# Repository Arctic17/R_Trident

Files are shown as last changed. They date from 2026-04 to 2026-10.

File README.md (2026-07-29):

<h1 align="left">
  <br>
  
  <br>
  R Trident: 
  
  High-Speed Rotary Delta Robot
</h1>

Every successful project starts with a goal, and this one is no different. My objective is to design and build a Rotary Delta kinematic motion system from the ground up covering feasibility research, groundwork, development, manufacturing, and programming, through to final assembly.
But why?
The purpose is twofold: to deepen my understanding of systems integration across multiple disciplines and to
refine my ability to manage every stage of a complex engineering project from start to finish.

So it can be summeriesed like this

R_Trident is a high-performance, direct-drive Rotary Delta Robot built using three **AC Servo Motors (A6M60-400H2B1-M17)** paired with real-time **EtherCAT** communications. The control system runs on a custom **Raspberry Pi** executing a hard **real-time** LinuxCNC kernel.

## System Architecture Overview

* **Host Controller:** Raspberry Pi CM5 (Real-Time Preempt Kernel)
* **Fieldbus:** EtherCAT (IgH EtherCAT Master Stack) @ 1ms loop time
* **Actuation:** 3x Direct-Drive 400W AC Servos (No gearboxes, peak torque 4.45 Nm)
* **Feedback Loops:** 17-bit absolute magnetic encoder feedback over CoE (CANopen over EtherCAT)

---

## Documentation Index

To read or modify specific engineering subsystems, navigate to the sub-files listed below:

1. [Mathematical Kinematics & Control Math](docs/01_mathematical_kinematics.md)
   * Spatial loops, 3D vector intersections, Simulink models, PID tuning data, and Z-axis trajectory bowing fixes.
2. [Mechanical Design & Topology Optimization](docs/02_mechanical_design.md)
   * Inventor 2025 System assembly and machined parts plans. Fusion 360 generative setup, weight metrics, load cases, filament selection.
3. [Electronics & Breakout Architecture](docs/03_electronics_breakout.md)
   * Dual Ethernet paths, isolated logic rails, buck converters, and headless hardware diagnostics interfaces.
4. [Electrical Cabinet Engineering](docs/04_electrical_cabinet.md)
   * 4-row layout, star distribution wiring, emergency interlocks without STO, and grounding trees.
5. [LinuxCNC & EtherCAT Drive Stack Setup](docs/05_linuxcnc_ethercat.md)
   * Host configuration, drive parameters, `ethercat-conf.xml` mapping, and `.hal` files.

## File structure

All custom files and entries in the BOM follow the **RT_XXX_YY_000_Name** naming system.

### Schema 
**`RT`** (Project) _ **`XXX`** (System) _ **`YY`** (Category) _ **`000`** (Index) _ **`Name`**

| System Code (XXX) | Description | Category Code (YY) | Description |
| :--- | :--- | :--- | :--- |
| **FRM** | Frame & Structure | **PR** | 3D Printed Part |
| **DRV** | Drive Train (Shoulder) | **MC** | Machined / Laser Cut |
| **ARM** | Biceps & Forearms | **CO** | Commercial (Off-the-shelf) |
| **EFF** | Effector & Hotend | **SK** | Skeleton / Reference |
| **BED** | Bed & Z-Axis | **AS** | Sub-Assembly |
| **ENC** | Enclosure | **EL** | Electronics Component |

---

## Project Navigation

* **`01_Management`**: Costs, Sourcing (Mädler/StepperOnline), and CDC.
* **`02_CAD`**: 
    * `00_Skeleton`: Master geometry and trig parameters.
    * `03_Parts_Custom`: All `RT_XXX_PR` and `RT_XXX_MC` files.
    * `05_Top_Assembly`: The "Digital Twin" (The complete machine).
* **`04_Electronics`**: Wiring schematics and pinout maps for the BIQU Manta.
* **`05_Firmware`**: Klipper `printer.cfg` and kinematic math.
* **`06_Outputs`**: Ready-to-print STLs and production drawings.

---

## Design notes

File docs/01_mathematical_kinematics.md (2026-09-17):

# 01. Mathematical Kinematics & Control Optimization

To start, we need to establish some groundwork. A standard machine uses a Cartesian motion system, where a movement in X requires only the corresponding axis to move to achieve a translation. While this can become complicated if different coordinate systems are used for the "World" and the Effector, that remains an edge case.

<div align="center">
<figure>
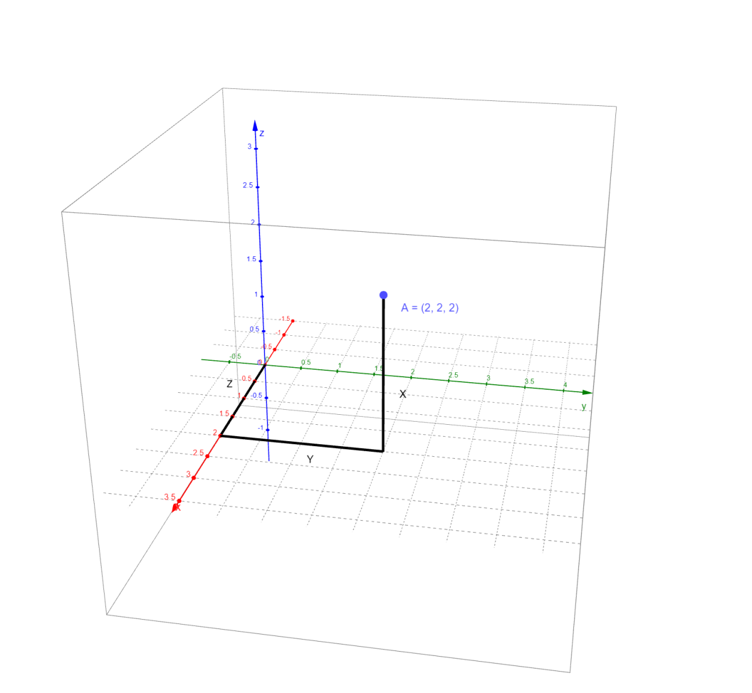
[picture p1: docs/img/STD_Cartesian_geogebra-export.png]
Standard cartesian representation of a point.
    
    <figcaption> 
        
        Example of a cartesian motion system.
</figcaption>
</figure>
</div>

Non-Cartesian systems, on the other hand, require mathematical computation to determine movement. A simple example is a two-link arm: a stick pivoting around a point with a second stick pivoting at its end. In this setup, you can reach any point in a 2D space. By knowing the angles of the two joints, you can calculate the coordinates of the end effector on the second link (SCARA).
This is the foundation of a Non-Cartesian system. It allows movement in 2D or 3D space but requires knowing the relative position of every part to extract the XYZ coordinates.

Delta systems are a subcategory where the "tool" (effector) is positioned in 3D space using three linkages that move along the same primary axes. By combining the movement of these three linkages, the effector's location is determined.
Rotary Deltas are a further sub-specialization, where the angle of a "bicep" and the lengths of the linked rods
dictate the final position.

## Spatial Kinematics Foundation

The Revolute-Input Delta Robot kinematics must be resolved using intersecting spheres in 3D coordinate space.

### The Vector Loop Equation

The primary equation for each of the three independent kinematic chains ($i = 1, 2, 3$) is modeled as:

$$\vec{B}_i + \vec{L}_i + \vec{l}_i = \vec{P}_e + \vec{P}_i$$

Where:

* $\vec{B}_i$: Vector from world coordinate origin to base joint $i$.
* $\vec{L}_i$: Vector representing the upper arm (bicep).
* $\vec{l}_i$: Vector representing the parallel spatial link (forearm pair).
* $\vec{P}_e$: Position vector of the tool-center point (TCP) end-effector.
* $\vec{P}_i$: Offset vector of joint attachment on the moving platform.

### Physical Design Constraints Matrix

* **Base Triangle Inscribed Radius ($s_B$):** 80 mm
* **Moving Platform Radius ($s_P$):** 35 mm
* **Upper Arm Length ($L$):** 150 mm
* **Lower Spatial Link Length ($l$):** 335 mm

---

## 2. Simulink modeling

To help with the complex mathematics used in this type of motion system a matlab project was created.
The systeme was split into multiple parts to aide in debugging. The parts are as followed 

* Main System View
  * Path generation
    * Random Pick and Place path generation.
    * Square path generation.
    * Circular path generation
  * Inverse Kinematics block translating ${x,y,z}$ coordinates to angles ${ \theta_1 , \theta_2 , \theta_3 }$.
  * PID
    * $PID_1$
    * $PID_2$
    * $PID_3$
  * Physical Model
    * Phsical-linkages$_1$
    * Phsical-linkages$_2$
    * Phsical-linkages$_3$
  * Forward Kinematics
  * Scopes

<div align="center">
<figure>
    
    <figcaption> MatLab Simulink model of the delta kinematics</figcaption>
</figure>
</div>

<div align="center">
<figure>
    
    <figcaption> MatLab Simscape model of the over all physical model linkages</figcaption>
</figure>
</div>

<div align="center">
<figure>
    
    <figcaption> MatLab Simscape model of the phsical linkages</figcaption>
</figure>
</div>

---

## 3. Path Tracking Dynamics & Z-Axis Bowing Correction

During fast linear XY translations, the end-effector can experience structural "bowing" along the Z-axis. This path error occurs because pure PID feedback loops react *after* tracking errors manifest.

### Velocity Feed-Forward (VFF)

To resolve this, the commanded trajectory velocity is passed through an active derivative block, scaled, and added directly to the control effort output:

```text
Commanded Pos ──> [Trajectory Planner] ──> Joint Angle ──> (+) ──> [Servo Drive]
                                               │           ^
                                               └──> [VFF] ─┘

```

Reference Control ParametersProportional Gain ($K_p$): 40
Integral Gain ($K_i$): 1.5
Derivative Gain ($K_d$): 4
Derivative Filter Coefficient ($N_d$): 100
Feed-Forward Coefficient ($K_{\text{vff}}$): 0.85

## Kinematic Architecture Flowchart

```mermaid
graph TD
    subgraph Coordinate Spaces
        W[World Origin 0,0,0] --> Bi[Base Joint Offset Vector: Bi]
        Bi --> Angle[Actuator Angle: theta_i]
        Angle --> L[Upper Arm Vector: Li]
        L --> Elbow[Elbow Joint Sphere Center]
    end

    subgraph Tool Platform
        TCP[Tool Center Point: Pe] --> Pi[Platform Joint Offset Vector: Pi]
        Pi --> Wrist[Wrist Joint Sphere Center]
    end

    Elbow ====>|Spatial Link Constraint: l| Wrist
```

# Mathematical Kinematics and Coordinate Frameworks for Rotary Delta Robot

This document establishes the geometric foundations, coordinate reference systems, and algebraic formulations required to model, simulate, and control the parallel kinematics engine of the high-speed Rotary Delta robot based on your custom physical dimensions.

Traditional 2D simplification methods (such as the law of cosines projected onto independent swinging planes) introduce severe kinematic warping when the robot transitions along its operational $X/Y$ boundaries. This warping occurs because the lower parallel linkages angle outwards into the 3D workspace domain. To guarantee micro-step tracking precision and eliminate path distortion, true spatial intersections are resolved algebraically using vector loop closures and intersecting sphere equations.

---

## System Geometry and Reference Frames

The architecture features a stationary upper platform (fixed base) and a translating lower platform (moving end-effector). Three symmetric closed-loop chains connect these platforms. Each chain consists of an actuated proximal link (bicep $L$) driven by a direct-drive servomotor and an unactuated parallel distal link (forearm parallelogram $l$).

### Coordinate Frame Assignments

* **Fixed Base Frame $\{B\}$:** The origin $O$ is positioned precisely at the planar center of the base platform. The $+Z_B$ axis points vertically upward, perpendicular to the base plane. The $+Y_B$ axis projects orthogonally toward the mid-point of the segment connecting revolute joint joints $B_2$ and $B_3$, forcing the first motor axis ($B_1$) to lie along the negative $Y_B$ axis.
* **Moving Platform Frame $\{P\}$:** The origin $P$ sits at the planar center of the moving end-effector platform. Because the parallelogram four-bar mechanisms eliminate all rotational degrees of freedom, the moving platform reference frame remains perfectly parallel to the fixed base frame across the entire reachable workspace ($[R_P^B] = I_3$).

### System Parameter Matrix

The following dimensional properties define your physical hardware build used for structural simulation, kinematic calculation, and control loop tuning:

| Variable | Mechanical Description | Value (mm) |
| :--- | :--- | :--- |
| $R_B$ | Base Pivot Circle Radius (Center to Motor Axis) | $80\text{ mm}$ |
| $R_P$ | End-Effector Radius (Center to Joint Axis) | $35\text{ mm}$ |
| $L$ | Upper Proximal Arm Length (Bicep) | $150\text{ mm}$ |
| $l$ | Lower Distal Arm Length (Forearm Parallelogram) | $335\text{ mm}$ |

---

## Vector Loop Closure Equations

For each of the independent arms ($i = 1, 2, 3$), a closed vector loop maps the geometric path from the central base origin to the tool center point (TCP) $P_e^B = [x, y, z]^T$:

$$\vec{B}_i^B + \vec{L}_i^B + \vec{l}_i^B = \vec{P}_e^B + [R_P^B]\vec{P}_i^P$$

Given that the orientation is constrained to translation-only ($[R_P^B] = I_3$), the vector equation simplifies to:

$$\vec{l}_i^B = \vec{P}_e^B + \vec{P}_i^P - \vec{B}_i^B - \vec{L}_i^B$$

### Fixed Base Angular Layout

The positions of the three base joints $\vec{B}_i^B$ are spaced symmetrically at $120^\circ$ intervals around the $Z_B$ axis at radius $R_B = 80\text{ mm}$:

$$\vec{B}_1^B = \begin{bmatrix} 0 \\ -R_B \\ 0 \end{bmatrix}, \quad \vec{B}_2^B = \begin{bmatrix} R_B\cos(30^\circ) \\ R_B\sin(30^\circ) \\ 0 \end{bmatrix}, \quad \vec{B}_3^B = \begin{bmatrix} -R_B\cos(30^\circ) \\ R_B\sin(30^\circ) \\ 0 \end{bmatrix}$$

Substituting $R_B = 80$:

$$\vec{B}_1^B = \begin{bmatrix} 0 \\ -80 \\ 0 \end{bmatrix}, \quad \vec{B}_2^B = \begin{bmatrix} 40\sqrt{3} \\ 40 \\ 0 \end{bmatrix}, \quad \vec{B}_3^B = \begin{bmatrix} -40\sqrt{3} \\ 40 \\ 0 \end{bmatrix}$$

### Moving Platform Connection Layout

The lower connection points $\vec{P}_i^P$ mapping the parallel joint attachments on the end-effector are defined relative to frame $\{P\}$ at radius $R_P = 35\text{ mm}$:

$$\vec{P}_1^P = \begin{bmatrix} 0 \\ -R_P \\ 0 \end{bmatrix}, \quad \vec{P}_2^P = \begin{bmatrix} R_P\cos(30^\circ) \\ R_P\sin(30^\circ) \\ 0 \end{bmatrix}, \quad \vec{P}_3^P = \begin{bmatrix} -R_P\cos(30^\circ) \\ R_P\sin(30^\circ) \\ 0 \end{bmatrix}$$

Substituting $R_P = 35$:

$$\vec{P}_1^P = \begin{bmatrix} 0 \\ -35 \\ 0 \end{bmatrix}, \quad \vec{P}_2^P = \begin{bmatrix} 17.5\sqrt{3} \\ 17.5 \\ 0 \end{bmatrix}, \quad \vec{P}_3^P = \begin{bmatrix} -17.5\sqrt{3} \\ 17.5 \\ 0 \end{bmatrix}$$

### Proximal Arm Joint Position

The bicep vector $\vec{L}_i^B$ is defined by the angular variables $\vartheta = [\theta_1, \theta_2, \theta_3]^T$, representing the motor rotation angles measured relative to the horizontal base plane:

$$\vec{L}_1^B = \begin{bmatrix} 0 \\ -L\cos\theta_1 \\ -L\sin\theta_1 \end{bmatrix}, \quad \vec{L}_2^B = \begin{bmatrix} L\cos\theta_2\cos(30^\circ) \\ L\cos\theta_2\sin(30^\circ) \\ -L\sin\theta_2 \end{bmatrix}, \quad \vec{L}_3^B = \begin{bmatrix} -L\cos\theta_3\cos(30^\circ) \\ L\cos\theta_3\sin(30^\circ) \\ -L\sin\theta_3 \end{bmatrix}$$

Substituting $L = 150$:

$$\vec{L}_1^B = \begin{bmatrix} 0 \\ -150\cos\theta_1 \\ -150\sin\theta_1 \end{bmatrix}, \quad \vec{L}_2^B = \begin{bmatrix} 75\sqrt{3}\cos\theta_2 \\ 75\cos\theta_2 \\ -150\sin\theta_2 \end{bmatrix}, \quad \vec{L}_3^B = \begin{bmatrix} -75\sqrt{3}\cos\theta_3 \\ 75\cos\theta_3 \\ -150\sin\theta_3 \end{bmatrix}$$

---

## Inverse Spatial Kinematics

The inverse kinematics problem calculates the required joint angles $\theta_i$ for a given tool coordinate $P_e^B = [x, y, z]^T$. Because the mechanical constraint locks each forearm parallelogram to a constant distance, the norm of the distal vector must always equal $l$ ($\|\vec{l}_i^B\|^2 = l^2$).

Substituting your vector definitions into the length constraint yields three independent scalar equations:

$$E_i\cos\theta_i + F_i\sin\theta_i + G_i = 0 \quad (i = 1, 2, 3)$$

Where the geometric constant terms for your specific dimensions ($L=150, l=335, R_B=80, R_P=35$) simplify to:

* **Arm 1:**
  $$E_1 = 2L(y + R_B - R_P) = 300(y + 45)$$
  $$F_1 = 2zL = 300z$$
  $$G_1 = x^2 + y^2 + z^2 + (R_B - R_P)^2 + L^2 - l^2 + 2y(R_B - R_P)$$
  $$G_1 = x^2 + y^2 + z^2 + 90y - 87700$$

* **Arm 2:**
  $$E_2 = -150\left(\sqrt{3}x + y - 45\right)$$
  $$F_2 = 300z$$
  $$G_2 = x^2 + y^2 + z^2 - 45\sqrt{3}x - 45y - 87700$$

* **Arm 3:**
  $$E_3 = 150\left(\sqrt{3}x - y + 45\right)$$
  $$F_3 = 300z$$
  $$G_3 = x^2 + y^2 + z^2 + 45\sqrt{3}x - 45y - 87700$$

### Trigonometric Half-Angle Substitution

To extract the raw angles without sign ambiguity, the equations are converted into a quadratic using the tangent half-angle substitution:

$$t_i = \tan\left(\frac{\theta_i}{2}\right), \quad \cos\theta_i = \frac{1 - t_i^2}{1 + t_i^2}, \quad \sin\theta_i = \frac{2t_i}{1 + t_i^2}$$

Substituting these terms into the compact form yields the standard quadratic equation:

$$(G_i - E_i)t_i^2 + (2F_i)t_i + (G_i + E_i) = 0$$

Solving for $t_i$ via the quadratic formula:

$$t_i = \frac{-F_i \pm \sqrt{F_i^2 - G_i^2 + E_i^2}}{G_i - E_i}$$

The joint angles are found directly by computing the inverse mapping:

$$\theta_i = 2\tan^{-1}(t_i)$$

### Physical Branch Selection

The quadratic formula yields two solutions per arm, representing the "knee-in" and "knee-out" mechanical configurations. To prevent collisions between the physical links and the moving platform, the controller enforces the **knee-out** branch by choosing the negative root option for the tracking loop.

---

## Forward Spatial Kinematics (Intersection of Three Spheres)

Direct kinematics calculates the operational position $[x, y, z]^T$ of the end-effector platform when the joint variables $\theta_i$ are provided. This is solved analytically by treating the end-effector position as the intersection point of three virtual spheres.

Given the joint angles $\theta_i$, the absolute spatial coordinates of the physical knee joints $\vec{A}_i^B$ are calculated directly using:

$$\vec{A}_i^B = \vec{B}_i^B + \vec{L}_i^B$$

By leveraging the fixed orientation property ($[R_P^B] = I_3$), three virtual sphere centers $\vec{A}_{iv}^B$ are defined by subtracting the moving platform vectors from the knee coordinates:

$$\vec{A}_{1v}^B = \begin{bmatrix} 0 \\ -80 - 150\cos\theta_1 + 35 \\ -150\sin\theta_1 \end{bmatrix} = \begin{bmatrix} 0 \\ -45 - 150\cos\theta_1 \\ -150\sin\theta_1 \end{bmatrix}$$

$$\vec{A}_{2v}^B = \begin{bmatrix} 40\sqrt{3} + 75\sqrt{3}\cos\theta_2 - 17.5\sqrt{3} \\ 40 + 75\cos\theta_2 - 17.5 \\ -150\sin\theta_2 \end{bmatrix} = \begin{bmatrix} 22.5\sqrt{3} + 75\sqrt{3}\cos\theta_2 \\ 22.5 + 75\cos\theta_2 \\ -150\sin\theta_2 \end{bmatrix}$$

$$\vec{A}_{3v}^B = \begin{bmatrix} -40\sqrt{3} - 75\sqrt{3}\cos\theta_3 + 17.5\sqrt{3} \\ 40 + 75\cos\theta_3 - 17.5 \\ -150\sin\theta_3 \end{bmatrix} = \begin{bmatrix} -22.5\sqrt{3} - 75\sqrt{3}\cos\theta_3 \\ 22.5 + 75\cos\theta_3 \\ -150\sin\theta_3 \end{bmatrix}$$

These vector centers are denoted as $[x_1, y_1, z_1]^T$, $[x_2, y_2, z_2]^T$, and $[x_3, y_3, z_3]^T$ respectively. The unknown TCP position then represents the common intersection point of three spheres, each having an identical radius equal to the forearm leg length $l = 335$:

$$(x - x_1)^2 + (y - y_1)^2 + (z - z_1)^2 = 335^2$$
$$(x - x_2)^2 + (y - y_2)^2 + (z - z_2)^2 = 335^2$$
$$(x - x_3)^2 + (y - y_3)^2 + (z - z_3)^2 = 335^2$$

### Linearization and Quadratic Simplification

Subtracting the third sphere equation from the first two eliminates the quadratic terms ($x^2, y^2, z^2$), transforming the system into a set of linear equations mapping $x$ and $z$ as functions of $y$:

$$a_{11}x + a_{12}y + a_{13}z = b_1$$
$$a_{21}x + a_{22}y + a_{23}z = b_2$$

Where the structural coefficients are calculated using the known centers:
$$a_{11} = 2(x_3 - x_1), \quad a_{12} = 2(y_3 - y_1), \quad a_{13} = 2(z_3 - z_1)$$
$$a_{21} = 2(x_3 - x_2), \quad a_{22} = 2(y_3 - y_2), \quad a_{23} = 2(z_3 - z_2)$$
$$b_1 = -x_1^2 - y_1^2 - z_1^2 + x_3^2 + y_3^2 + z_3^2$$
$$b_2 = -x_2^2 - y_2^2 - z_2^2 + x_3^2 + y_3^2 + z_3^2$$

Solving this linear system maps $x$ and $z$ as explicit linear expressions of $y$:

$$x = a_4y + a_5, \quad z = a_6y + a_7$$

Substituting these linear relationships back into the first sphere equation yields a single quadratic equation focused entirely on the $y$ coordinate:

$$ay^2 + by + c = 0$$

The two resulting roots are computed using the quadratic formula:

$$y_{\pm} = \frac{-b \pm \sqrt{b^2 - 4ac}}{2a}$$

### Physical Workspace Filtering

Substituting $y_{\pm}$ back into the linear relations yields two complete spatial coordinate sets ($P_{e+}^B$ and $P_{e-}^B$). The kinematics engine filters these options by selecting the solution that places the end-effector platform below the fixed base plane ($z < 0$), ensuring a valid configuration within the physical workspace.

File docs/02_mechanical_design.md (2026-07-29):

# 02. Mechanical Design & Topology Optimization

## Direct-Drive Mass Optimization Strategy
The robot is compriesed of a direct drive motion system. this is deu to sevral factors. The first of which is the cost of a gear box with axeptibal backlash is far out of buget. this eliminates any lower cost planetary or other gearbox system. Secondly a belt driven approche was considered but due to the added cost and complexity it was scrached. this also leaves room for future development. Due to the choice of gearbox-less direct drive, the motor rotor directly experiences the unbuffered load inertia of the entire arm assembly ($J_{\text{reflected}} = J_{\text{load}}$). The main mechanical goal is to prioritize **mass minimization**. A particulare attentions was given to the elbow joint to avoid high-frequency servo oscillations and inertia mismatch errors.

---

## Fusion 360 Generative Design Criteria

The upper bicep arm structure is optimized using automated generative algorithms inside Fusion 360 based on the following targets:

| Boundary Constraint Parameter | Value Limit Set |
| :--- | :--- |
| **Target Envelope Mass Limit** | 60g – 75g (Plastic body only) |
| **Structural Factor of Safety** | 2.0 to 2.5 (Anisotropic scaling adjustment) |
| **First Fundamental Modal Frequency** | $\ge 130\text{ Hz}$ (To bypass encoder noise) |
| **Maximum Displacement / Deflection** | 0.5 mm under peak motor acceleration torque |

> **Note:** Explicitly disable *Elastic Buckling* and *Thermal Stress Constraints* within the study parameters to prevent unnecessary solver loops.

---

## Load Case Models

1. **Load Case A (Peak Dynamic Torsion):** 45 N applied tangentially to the elbow joint axis (derived from motor peak acceleration torque of 4.45 Nm).
2. **Load Case B (Forearm Tension/Compression):** 45 N acting axially through the linkage mounting interface points.
3. **Load case C (Complex Torsion):** The actual torque value of 4.45 Nm was applyed round the motor shaft using the key way and constrained on the linkage mounting interface.

---

## Materials Selection & Joinery Architecture

* **Filament Selection:** **Nylon-GF30** (30% Glass Fiber Reinforced Nylon). Nylon-GF provides excellent cyclic fatigue resistance and structural damping. Standard PLA-CF must be rejected due to severe long-term material creep under mechanical fastener torque, which introduces joint backlash.

## Study outcomes
<div align="center">
<figure>
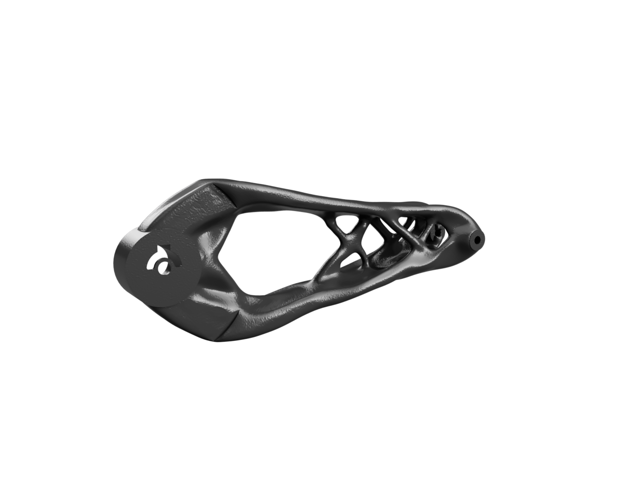
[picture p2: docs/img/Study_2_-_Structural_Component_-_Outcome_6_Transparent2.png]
    
    <figcaption> MatLab Simscape model of the phsical linkages</figcaption>
</figure>
</div>

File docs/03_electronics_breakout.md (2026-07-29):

# 03. Electronics & Custom CM5 Carrier PCB Architecture

## Electronics Assembly & COTS Breakout Integration

Because a custom carrier PCB is omitted from the final deployment, the control architecture utilizes a Commercial Off-The-Shelf (COTS) **Waveshare Compute Module 5 IO Board** paired with DIN-rail industrial breakout enclosures. This maintains professional isolation without custom fabrication cycles.

---

## 1. Physical Mount & IO Shielding Strategy

* **Baseplate Isolation:** The CM5 IO Board must be secured to a 3D-printed DIN-rail mounting cradle to electrically isolate its exposed solder points from the metallic cabinet back panel.
* **Ribbon Traps:** The 40-pin GPIO pin assembly uses a shielded flat ribbon cable routed directly to a terminal block module on the DIN rail. This removes terminal strain from the Raspberry Pi pins.

---

## 2. Power Rail Distribution (COTS Components)

Instead of an onboard integrated buck circuit, the power network uses an independent, isolated **Mean Well DDR-30G-5** (24V to 5V 6A) DIN-rail DC-DC converter:

* **Separation Rules:** The input side taps straight into the primary 24V DC logic line protected by a 6A breaker. 
* **Core Feed:** The 5V DC output connects directly to the screw terminal power inputs on the IO board, bypassing the fragile USB-C power input port to ensure a low-resistance connection.

---

## 3. High-Speed Communication Routing

* **Primary Real-Time Link (Eth0):** Connected straight via Cat6 SFTP (Shielded Foiled Twisted Pair) patch cable from the native RJ45 socket to the Input port of Servo Drive 1. 
* **User-Space Network Bridge:** A standard USB-to-Ethernet dongle (utilizing an ASIX or Realtek chipset) occupies a USB 3.0 slot on the IO board. This secondary line acts as your clean debugging/SSH point, keeping local network traffic isolated from the real-time EtherCAT processing thread.

---

## 4. Hardware Diagnostics Interface

* **I2C Core Connections:** Pins 3 (SDA) and 5 (SCL) on the 40-pin ribbon connector run to a DIN-mounted SSD1306 OLED screen enclosure.
* **Field Relays:** Low-power GPIO output pins drive an optoisolated 4-channel DIN relay bank. The optocoupler isolation chips prevent any back-EMF spikes from inductive brake coils from making physical contact with the CM5 silicon processing cores.

Hardware Interconnect Architecture
Code snippet
graph TD
    subgraph Waveshare CM5 IO Baseboard
        CM5[Raspberry Pi CM5 Core]
        Net1[Native RJ45 Port: Eth0]
        Net2[USB 3.0 Bus Interface]
        GPIO[40-Pin GPIO Header]
    end

    subgraph DIN Rail Layer
        StepDown[24V-to-5V 5A DIN Power Module] -->|Stable Core Power| CM5
        Mesa[DIN Breakout Board]
        Relay[DIN Relay Array]
        OLED[SSD1306 Diagnostic Screen]
    end

    subgraph Industrial Network Bus
        Net1 ===>|Raw EtherCAT Sync Loop| Drive1[Servo Drive 1]
        Drive1 ===> Drive2[Servo Drive 2]
        Drive2 ===> Drive3[Servo Drive 3]
        Net2 -->|Isolated LAN / SSH Access| Debug[External Debugging Router / PC]
    end

    GPIO -->|Ribbon Cable| Mesa
    Mesa -->|Optocoupled Output| Relay
    Mesa -->|I2C Bus Protocol| OLED
    Relay -->|24V Coil Control| Brakes[Motor Friction Brakes]

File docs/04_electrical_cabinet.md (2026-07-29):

# 04. Electrical Cabinet Engineering & Infrastructure

## 4-Row Physical Component Layout

The enclosure layout separates high-power electrical noise from low-voltage control signals using a vertical layout approach:

```text
+-------------------------------------------------------------+
| [Row 1] LOW-VOLTAGE CONTROL                                 |
|  - Raspberry Pi CM5 Controller, WAGO Bus Coupler Train      |
+-------------------------------------------------------------+
| [Row 2] DISTRIBUTION & SAFETY                               |
|  - Rotary Disconnect, Breakers, Moeller Safety Contactor     |
+-------------------------------------------------------------+
| [Row 3] HIGH-POWER SERVO DRIVES                             |
|  - 3x StepperOnline A6-EC Drives (50mm Top/Bottom Clearance)|
+-------------------------------------------------------------+
| [Row 4] FIELD WIRING TERMINAL RAIL                          |
|  - Left: Clean Low-Voltage Field Signals | Right: High-Volt |
+-------------------------------------------------------------+
```

## Power Distribution & Breaker Bill of Materials

To prevent high-current inductive inductive spikes (e.g., from mechanical brake coils) from causing logic voltage drops on the host controller, use a dedicated star-wiring configuration back to the main power supply output terminals.

### Circuit Protection Ratings

- Main AC Line Supply Input: 1x 13A Curve C Miniature Circuit Breaker (MCB)

- Servo Drives AC Input Lines: 3x 6A Curve C Miniature Circuit Breakers

- 24V Logic Power Supply Unit: 1x 6A Curve C Miniature Circuit Breaker

## Emergency Interlock Loop & Safety Design

Because the StepperOnline A6-EC drives lack built-in Safe Torque Off (STO) inputs, a hardware-level safety layer must be wired into the panel supply:

- The Circuit: Wire a dual-channel Normally Closed (NC) latching Emergency Stop button in series directly with the 24V DC coil of the 3-pole master AC contactor (Moeller DILMC7-10).

- The Function: Pressing the E-stop cuts the coil power, opening the main contacts and removing AC power from the three servo drives. This stops motor motion while maintaining the separate 24V DC logic rail for controller feedback.

## Grounding and Noise Suppression

- Star Grounding Tree: Connect the motor power cable's green/yellow ground wire and the braided shield layer directly to the PE terminal block on the drive chassis. Run an independent ground wire from each drive's ground stud to the main copper busbar in the cabinet. Do not daisy-chain ground wires between drives.

- Inductive Brake Suppression: Connect a high-voltage flyback diode (e.g., 1N4007) in reverse-bias directly across the terminals of each mechanical brake relay contact to clip high-voltage spikes during inductive switching.

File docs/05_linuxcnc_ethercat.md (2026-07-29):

# 05. LinuxCNC & EtherCAT Real-Time Driver Stack

## 1. Host Network Configuration

Run these configuration steps to bind your real-time network adapter to the IgH EtherCAT driver stack.

1. Edit the core master system configuration file:

```bash
   sudo nano /etc/ethercat.conf
```

Set your dedicated port's MAC address and specify the generic network driver module:

```bash 
MASTER0_DEVICE="00:11:22:33:44:55"
DEVICE_MODULES="generic"
```
Prevent standard Linux network managers from interacting with the dedicated interface:

```bash
sudo nano /etc/NetworkManager/NetworkManager.conf
```
Append the following device exclusion keyfile entry:

```bash
[keyfile]
unmanaged-devices=mac:00:11:22:33:44:55
```

Restart the low-level communication service daemon:
```bash
sudo systemctl restart ethercat
```

Verify that the network hardware path can view all three connected axes down the wire:

```bash
ethercat slaves
```

## Servo Drive Firmware Configuration

Configure these baseline parameters using the physical hardware keypad on each individual A6-EC drive:

- C00.00 = 10 : Sets primary operation control mode to EtherCAT bus control.

- C13.01 = 1 (Axis 2 = 2, Axis 3 = 3) : Assigns sequential Node Station Aliases down the physical daisy chain line.

- C13.05 = 1 : Standardizes Distributed Clocks (DC) Mode 1 for sub-microsecond synchronization.

Important: To commit these settings to the non-volatile memory, navigate to parameter 31.01 within the F (Function) menu, set the value to 1, and hold down the Enter key for 3–5 seconds until the screen flashes StArt followed by FinisH. Cycle the main power afterwards.

## Configuration Setup Files

ethercat-conf.xml

```xml

<master idx="0" appTimePeriod="1000000" refClockSyncCycles="1">
  <slave alias="0" position="0" vendor="0x00000000" product="0x00000000" id="axis1">
    <syncManager idx="2" dir="out" watch="1">
      <pdo idx="0x1702"/>
    </syncManager>
    <syncManager idx="3" dir="in" watch="0">
      <pdo idx="0x1b02"/>
    </syncManager>
  </slave>
  </master>

```

Rotary_Delta.hal

```text
# Load the LinuxCNC Real-Time Motion Module
loadrt motmod servo_period=1000000 joints=3

# Load the Low-Level EtherCAT Driver Wrapper Component
loadusr -W lcec_conf ethercat-conf.xml
loadrt lcec

# Link Driver Real-Time Execution Threads to Servo Interrupt Clocks
addf lcec.read-all servo-thread
addf motion-command-handler servo-thread
addf motion-controller servo-thread
addf lcec.write-all servo-thread

# Establish Simple Hardware Loop Testing Interlinks (Axis 1 Example)
net ax1-pos-cmd  joint.0.motor-pos-cmd  => lcec.0.axis1.pos-cmd
net ax1-pos-fb   lcec.0.axis1.pos-fb    => joint.0.motor-pos-fb
```

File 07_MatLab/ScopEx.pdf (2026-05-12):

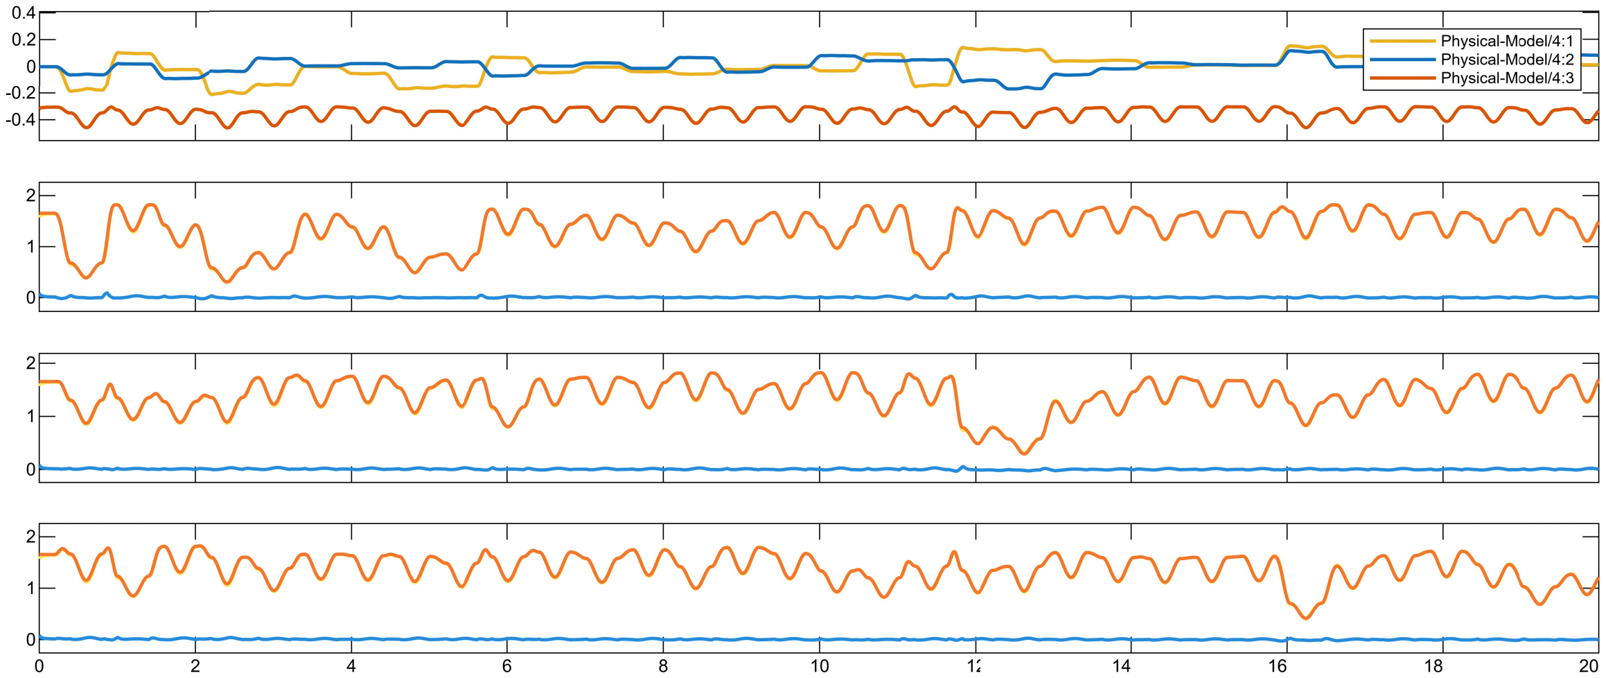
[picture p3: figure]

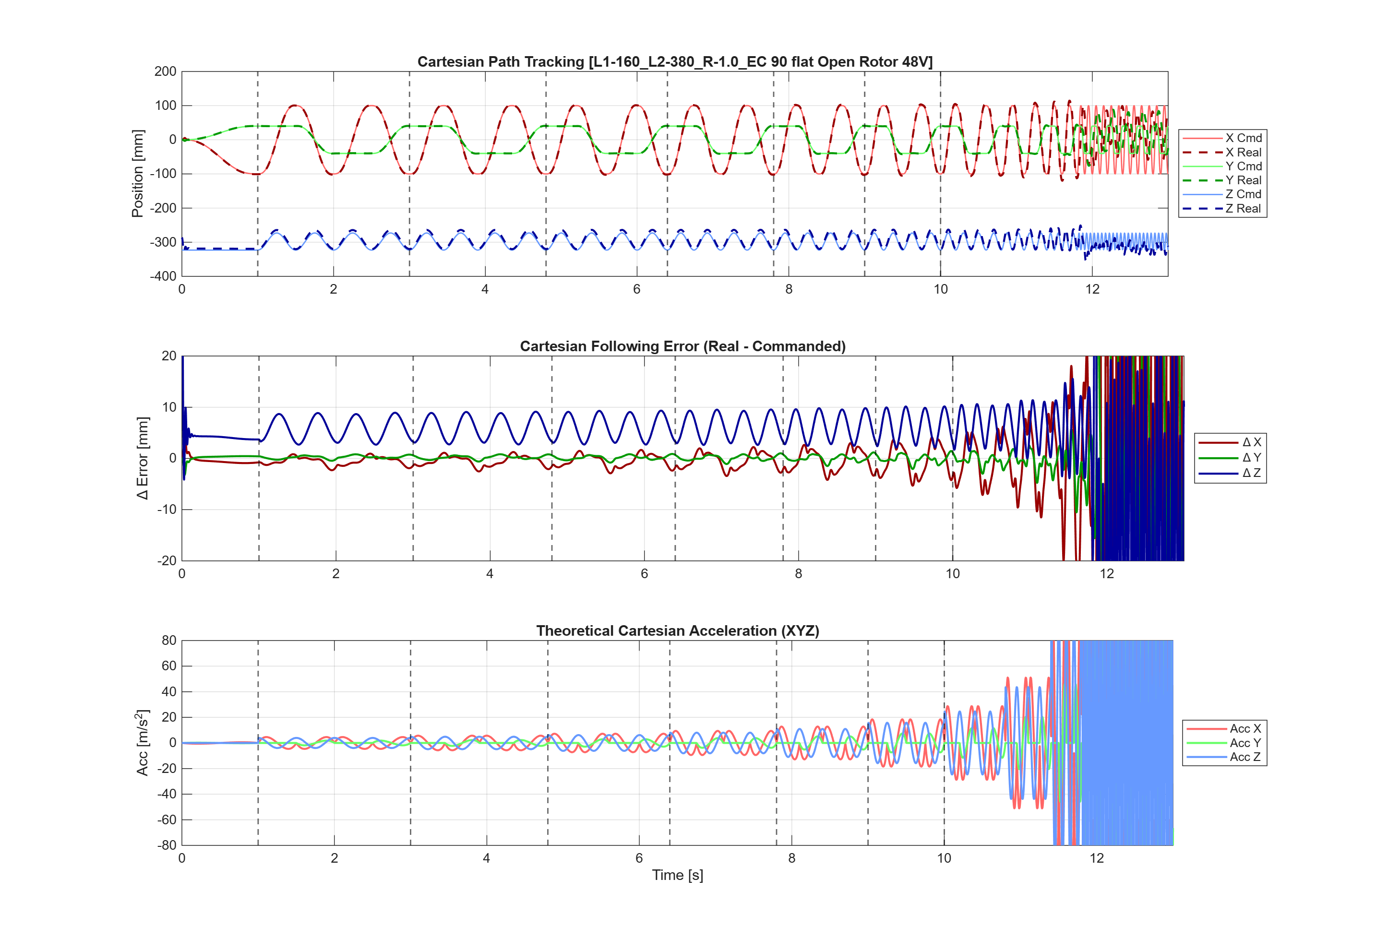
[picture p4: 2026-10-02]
07_MatLab/MotorValidation/Single_Run_Results/R200_L1-160_L2-380_R-1.0_EC 90 flat Open Rotor 48V/R200_L1-160_L2-380_R-1.0_EC 90 flat Open Rotor 48V_Kinematics.png

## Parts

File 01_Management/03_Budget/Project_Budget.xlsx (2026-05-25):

Phase | Phase Name | Task ID | Task Description | Estimated Hours | Actual Hours | Estimated Cost (CHF) | Actual Cost (CHF)
1 | Simulation | T_1_1 | Grasp and understand the kninematics | 10 | 12 | 0 | 0
 |  | T_1_2 | Create a numerical twin in simscape | 12 | 18 | 0 | 0
 |  | T_1_3 | optimise arm lengths and tune PID | 4 | 2 | 0 | 0
 |  | T_1_4 | Take and read force valeus seen by the system | 6 | 2 | 0 | 0
 |  | T_1_5 | do some rough FEMM simulations to test feasability | 10 | 4 | 0 | 0
 |  | T_1_6
 |  | T_1_7
 |  | T_1_TOT |  | 42 | 38 | 0 | 0
2 | Mechanical & Electronics Design | T_2_1 | Motor Selection and Purchases | 8 | 8 | 400
 |  | T_2_2 | Frame | 4 | 12 | 400
 |  | T_2_3 | Motor to Arm linkage | 2 |  | 50
 |  | T_2_4 | Bicep | 4 |  | 50 |  | Task ID | Phase | Task Description | Estimated Hours | Actual Hours | Variance (Hours) | Estimated Cost (CHF) | Actual Cost (CHF)
 |  | T_2_5 | Forearm (Ball joint incl.) | 6 |  | 100 |  | T1 | Simulation & Design | Kinematic & Dynamic Modeling in Simulink | 30 | 0 | 30 | #ERROR! | A2\ | Bill_of_Materials!F:F) | 0
 |  | T_2_6 | Effector | 8 |  | 60 |  | T2 | Simulation & Design | Path Generation & Trajectory Smoothing (S-Curve/30G Optimization) | 20 | 0 | 20 | #ERROR! | A3\ | Bill_of_Materials!F:F) | 0
 |  | T_2_7 | Saftey Critical Features | 8 |  | 100 |  | T3 | Mechanical | Procurement of 80x80 Profiles and Hardware | 10 | 0 | 10 | #ERROR! | A4\ | Bill_of_Materials!F:F) | 0
 |  | T_2_8 | PLC | 16 |  | 400 |  | T4 | Mechanical | Machining & Mounting 10mm HPL Vulcano Base Plate | 15 | 0 | 15 | #ERROR! | A5\ | Bill_of_Materials!F:F) | 0
 |  | T_2_9 | PLC I/O | 4 |  | 100 | 153 | T5 | Mechanical | Assembling Carbon Fiber Arms & Ball Joints (150mm/300mm) | 12 | 0 | 12 | #ERROR! | A6\ | Bill_of_Materials!F:F) | 0
 |  | T_2_10 |  |  |  |  |  | T6 | Electronics | Wiring StepperOnline T6 Servos & Power Supplies | 15 | 0 | 15 | #ERROR! | A7\ | Bill_of_Materials!F:F) | 0
 |  | T_2_11 |  |  |  |  |  | T7 | Electronics | Implementing DC E-Stop Safety & Mechanical Brakes | 8 | 0 | 8 | #ERROR! | A8\ | Bill_of_Materials!F:F) | 0
 |  | T_2_12 |  |  |  |  |  | T8 | Control & EtherCAT | Setting up TwinCAT 3 Real-Time Kernel on Legion Laptop | 25 | 0 | 25 | #ERROR! | A9\ | Bill_of_Materials!F:F) | 0
 |  | T_2_13 |  |  |  |  |  | T9 | Control & EtherCAT | Mapping Drive ESI Files & Tuning 17-bit CSP Loops | 20 | 0 | 20 | #ERROR! | A10\ | Bill_of_Materials!F:F) | 0
 |  | T_2_14 |  |  |  |  |  | T10 | Academic | Website Documentation & Final Project Report Writing | 40 | 0 | 40 | #ERROR! | A11\ | Bill_of_Materials!F:F) | 0
 |  | T_2_TOT |  | 60 | 20 | 1660 | 153 | T10 | Academic | Website Documentation & Final Project Report Writing | 40 | 0 | 40 | #ERROR! | A11\ | Bill_of_Materials!F:F) | 0
 |  |  |  |  |  |  |  | TOTAL |  | Total Project Summary | 195 | 0 | 195 | #ERROR! | 0
 |  |  |  |  |  |  |  | #ERROR!
 |  |  |  |  |  |  |  | Part ID | Component Name | Supplier | Qty | Unit Cost (CHF) | Total Cost (CHF) | Link to Task ID | Status
 |  |  |  |  |  |  |  | P1 | StepperOnline T6 EtherCAT Servo Motors + Drives (400W) | StepperOnline | 3 | 120 | 0 | T6 | Ordered
 |  |  |  |  |  |  |  | P2 | 80x80 Aluminum Profiles & Fasteners | Local Supplier | 1 | 90 | 0 | T3 | Planned
 |  |  |  |  |  |  |  | P3 | 10mm HPL Vulcano Base Plate | Local Supplier | 1 | 45 | 0 | T4 | Planned
 |  |  |  |  |  |  |  | P4 | Carbon Fiber Tubes & High-Precision Ball Joints | Aliexpress/Hobby | 1 | 50 | 0 | T5 | Planned
 |  |  |  |  |  |  |  | P5 | Heavy Duty DC Power Supply (Drive Power) | Distrelec | 1 | 65 | 0 | T6 | Planned
 |  |  |  |  |  |  |  | P6 | Latching E-Stop Button + Safety Contactor | Distrelec | 1 | 25 | 0 | T7 | Planned
 |  |  |  |  |  |  |  | P7 | Shielded Cat6 SFTP Cables (EtherCAT Network) | Local Shop | 4 | 5 | 0 | T8 | Planned
 |  |  |  |  |  |  |  | P8 | Misc. Hardware (M8 Bolts\ | T-Nuts\ | Cable Ties) | Hardware Store | 1 | 20 | 0 | T3 | Planned

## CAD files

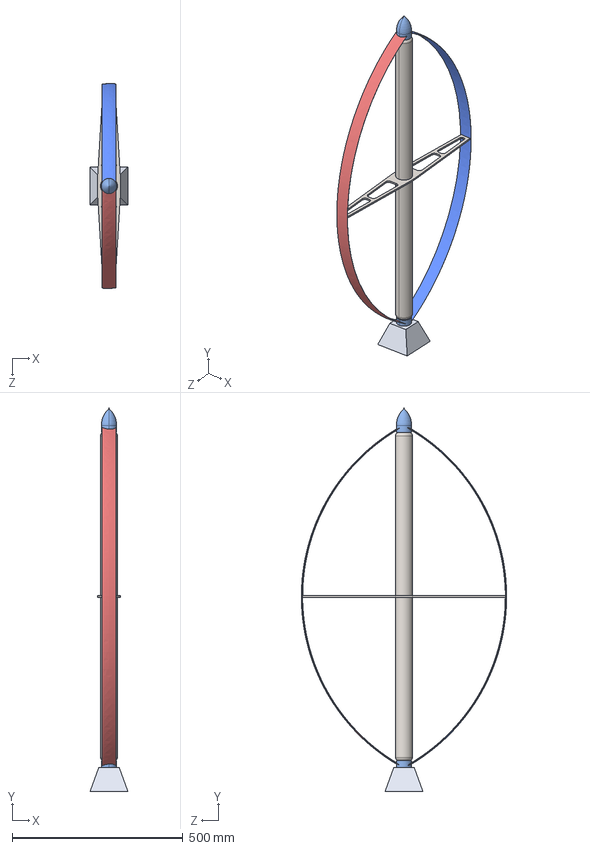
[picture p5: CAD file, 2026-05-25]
02_CAD/08_Template/VisAssemblage-Tutoriel-FixationEolienne/Darrieus Turbine Assy.STEP
111.0 x 1120.0 x 600.7 mm
Selonsong Darrieus
Airfoil Darieus NACA 63-212
Box Bawah

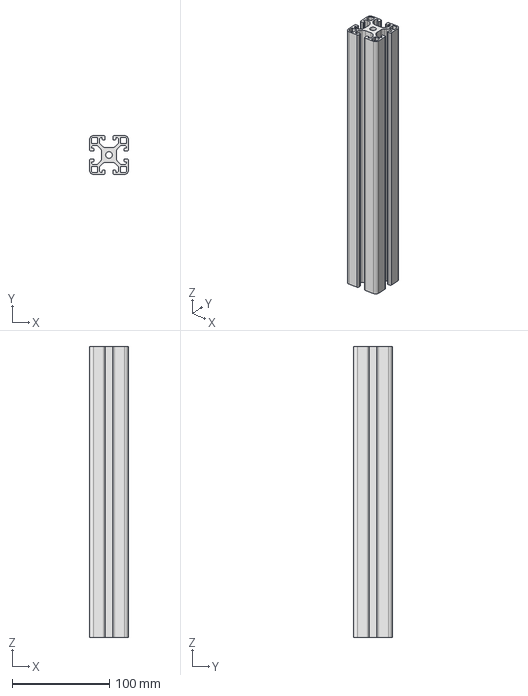
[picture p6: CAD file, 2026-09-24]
02_CAD/01_Standard_Parts/02_FRM_FULL_Frame_V1/40x40L I-Type slot 8/P40L_N8_I.stp
40.0 x 40.0 x 300.0 mm

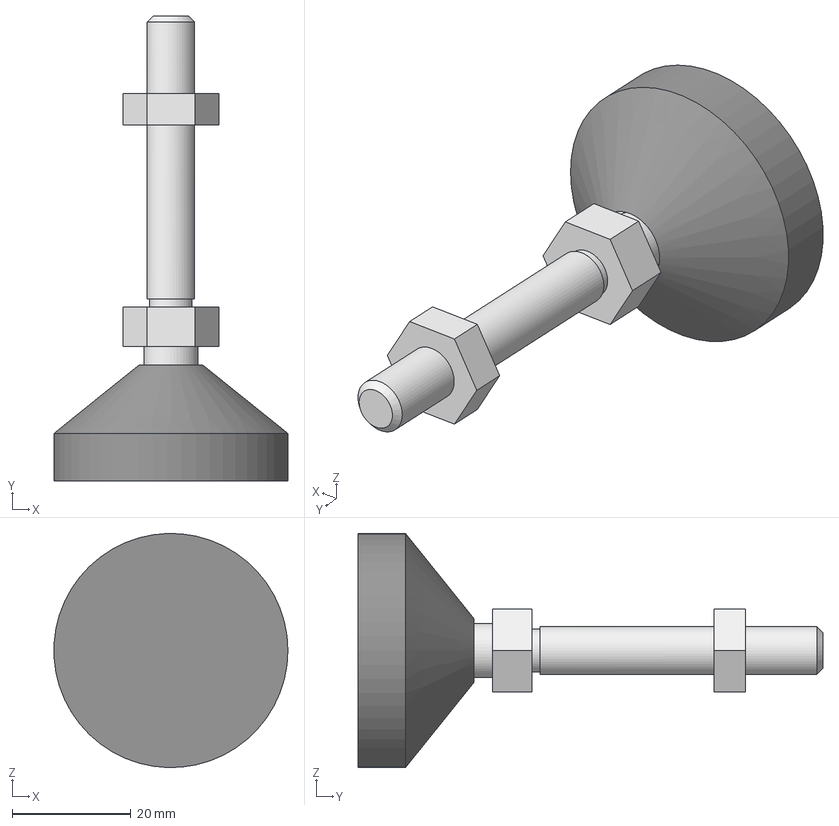
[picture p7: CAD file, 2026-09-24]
02_CAD/01_Standard_Parts/02_FRM_FULL_Frame_V1/BD40-8x50/BD40-8x50.stp
39.4 x 78.2 x 39.4 mm
M8 Thread L50
Base50
NutM8

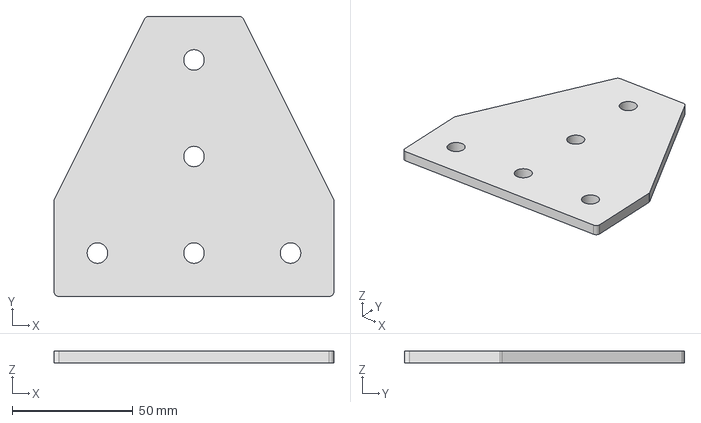
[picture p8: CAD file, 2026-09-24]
02_CAD/01_Standard_Parts/02_FRM_FULL_Frame_V1/Motedis_LP40111_3/Motedis_LP40111.stp
116.0 x 116.0 x 5.00 mm

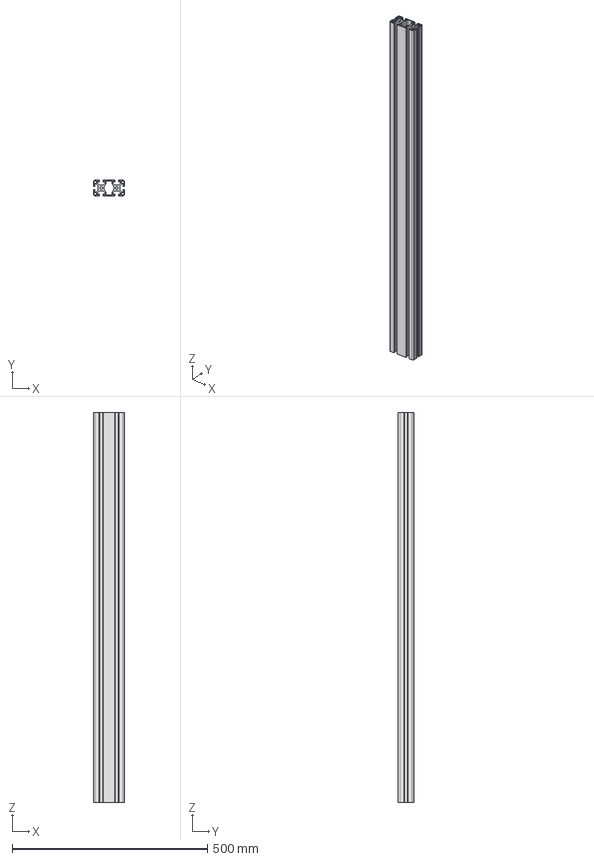
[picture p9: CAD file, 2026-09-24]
02_CAD/01_Standard_Parts/02_FRM_FULL_Frame_V1/Motedis_Profile 40x80L I-Type slot 8.stp
80.0 x 40.0 x 1000.0 mm

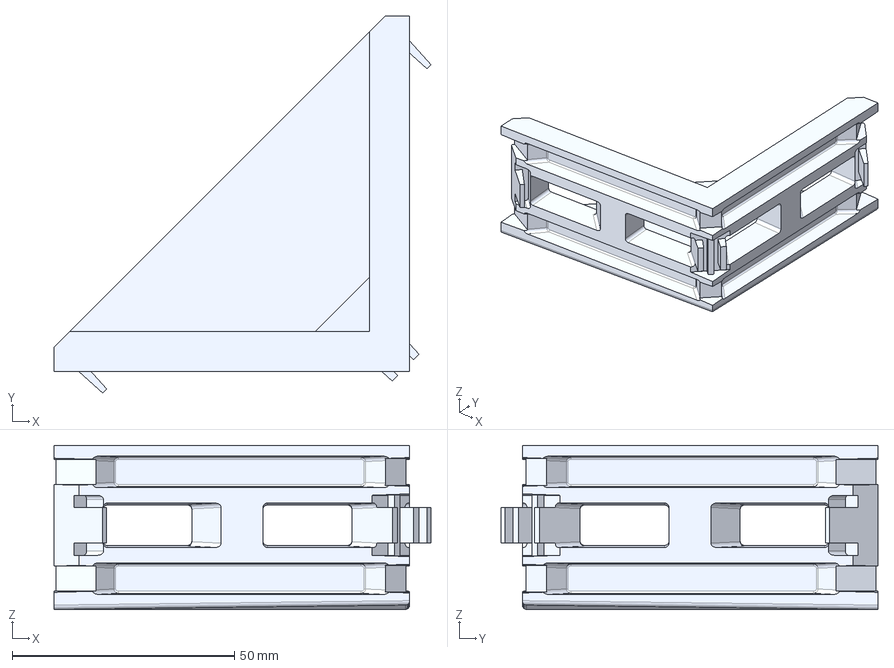
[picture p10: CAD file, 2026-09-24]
02_CAD/01_Standard_Parts/02_FRM_FULL_Frame_V1/Motedis_S8IBR4080/Motedis_S8IBR4080.stp
84.8 x 84.8 x 37.0 mm

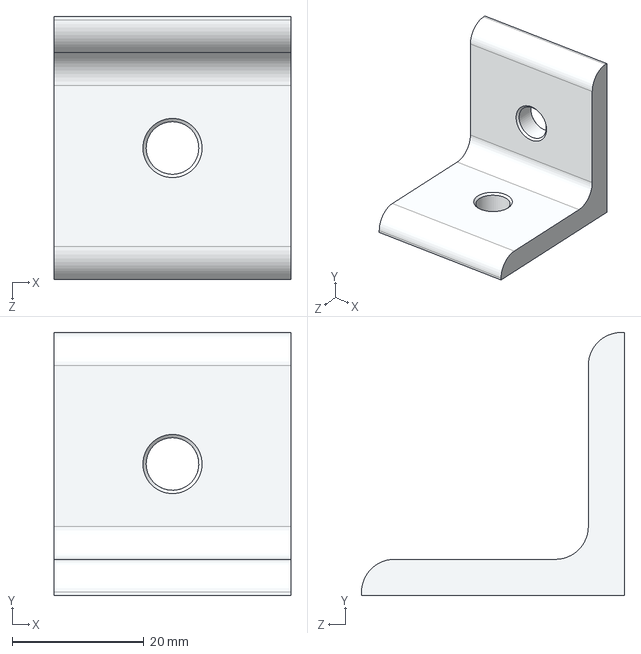
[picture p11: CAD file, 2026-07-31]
02_CAD/01_Standard_Parts/03_FRM_Fastener/3760_20240902141114_4040L-ALU.STEP
36.0 x 40.0 x 40.0 mm

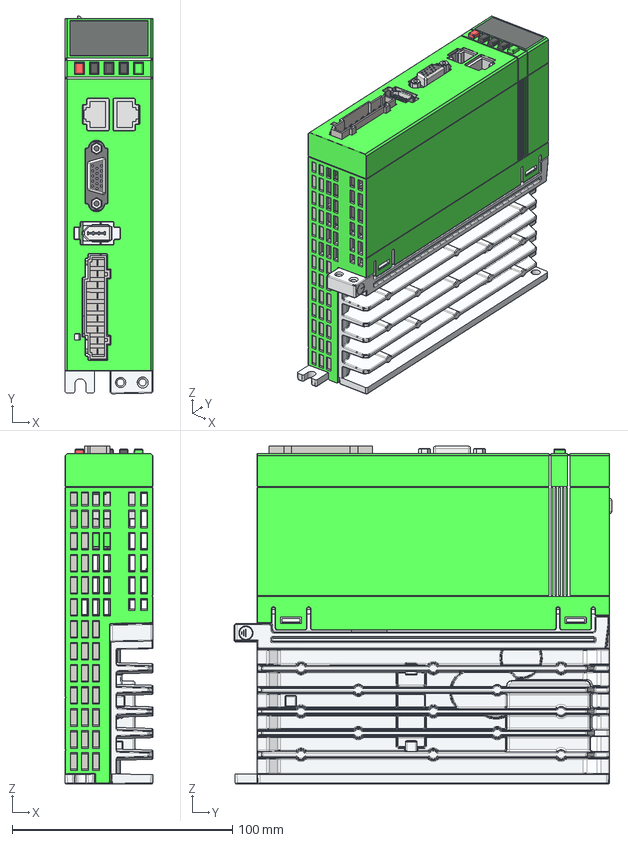
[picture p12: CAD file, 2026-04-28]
02_CAD/01_Standard_Parts/04_ELE_Electrical_Automation/A6-400EC/A6-400EC.stp
40.0 x 171.3 x 153.3 mm
C30190041A1
C02010298A0-FINAL
CON2X16-RJ45-2_54-28_3-17_2-D0_
CON2X2-3_5-3_5-8_4X14-D1_4
CON9-197-47X18_1-D1_4
USB6-2_0-18_1X8_4-D0_8-BA-A
USB16-TYPEC-0_5MM-8_94X7_85-SMD
DB15-90-100-30_8X21_9-D1
C02010299A0-AS700-KD1_A0-12-14
SR0402 x 33
SC0402 x 17
SC0805
SOP16-50-150 x 3
SOT23 x 6
DIS13-100-300-23X10-D0_8-A
MARK-A x 3
TP60A x 9
SSW4-118-4_5X4_5-SMD x 5
C30200041A1
C31030027A1
C30360018A0
C31030028A1
C31030029A1

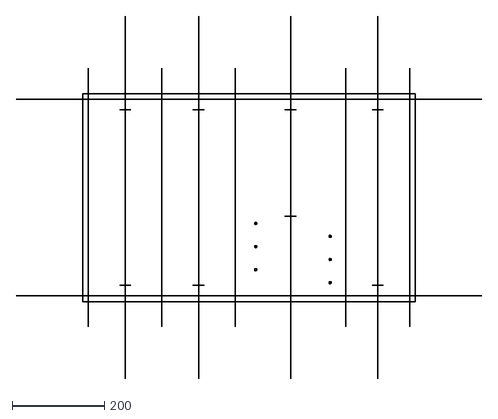
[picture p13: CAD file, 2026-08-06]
02_CAD/01_Standard_Parts/04_ELE_Electrical_Automation/LaserCutGuide.dxf
1008.0 x 784.7

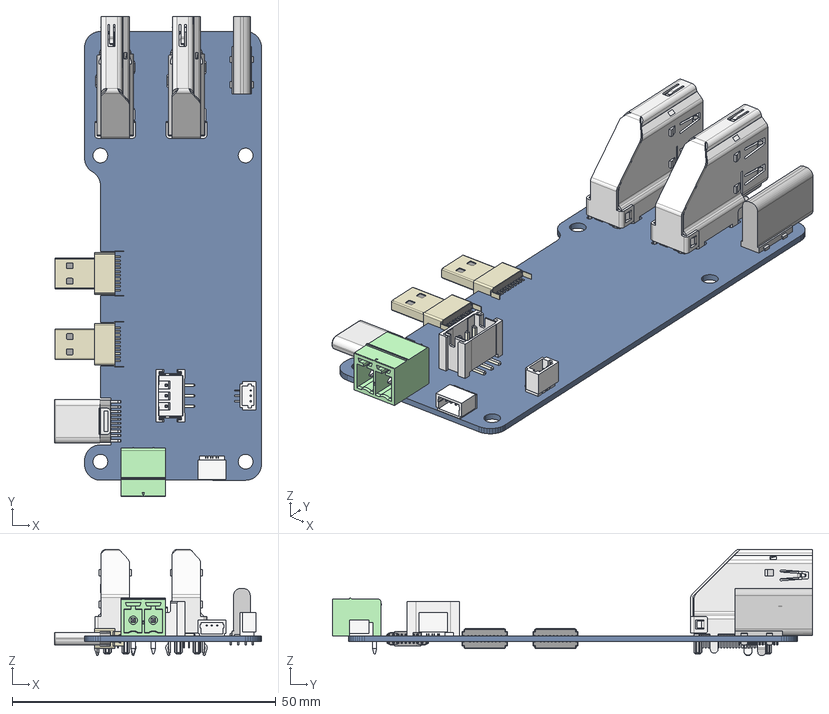
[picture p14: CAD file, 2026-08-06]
02_CAD/01_Standard_Parts/04_ELE_Electrical_Automation/Pi5/Pi5-Connector-Adapter.stp
39.2 x 91.0 x 20.1 mm
HDMI_TYPE_C_ADAPTER_PCB-240308
HDMI-MICRO--19P000 x 2
TYPEC-16P--H0001
HDMI_90D-SIDE x 2
TYPE-C_CY-JTF4-14PA-900
USER_LIBRARY-DS1066-04-3MSV6_1
KEFA_3_81MM_2PIN_MALE_RA
PITCH1MM-3PIN-SMT-WO
PITCH1MM-3PIN-SMT-L

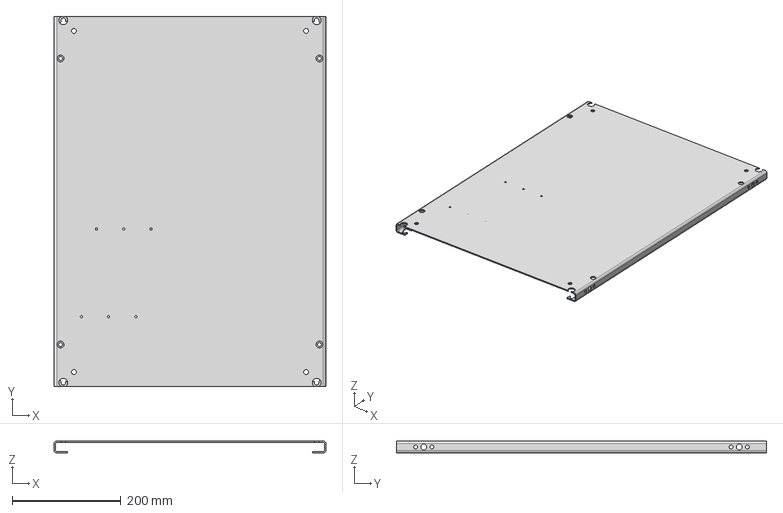
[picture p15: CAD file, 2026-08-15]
02_CAD/01_Standard_Parts/04_ELE_Electrical_Automation/VX 8617540/8617_540_P1.stp
499.0 x 679.0 x 22.0 mm

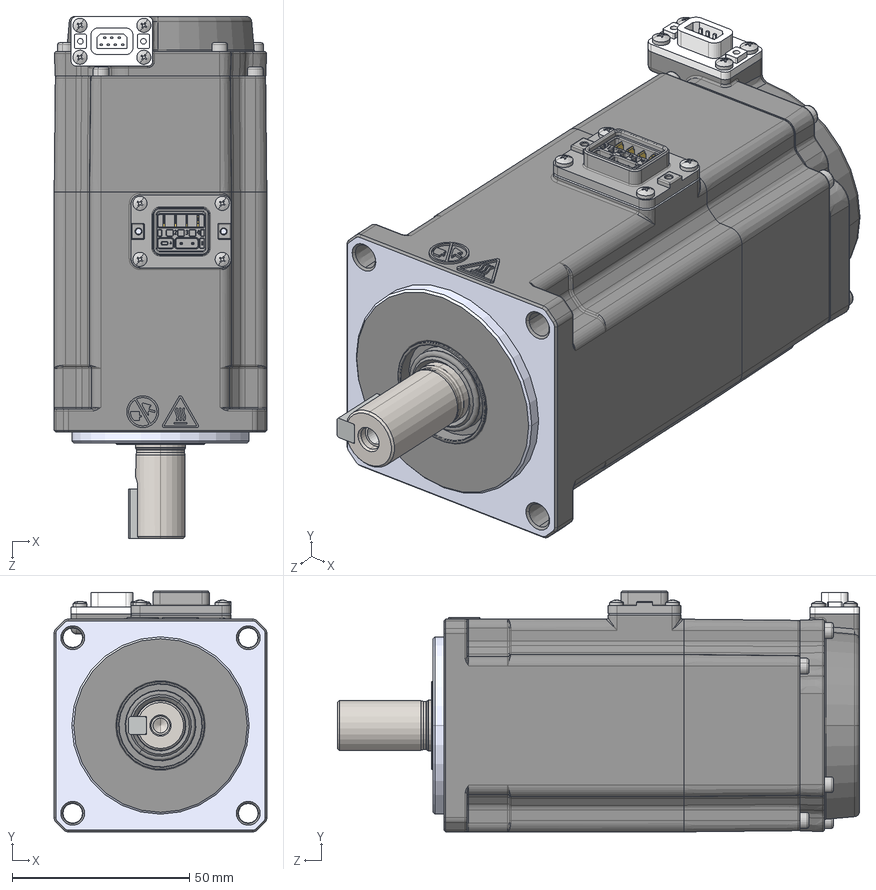
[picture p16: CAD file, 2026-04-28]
02_CAD/01_Standard_Parts/A6M60-400H2B1-M17/A6M60-400H2B1-M17.STEP
60.0 x 67.9 x 147.2 mm
2142000001_机壳毛坯_RSK1-H060A04B30S36
2174000002_后端盖毛坯_RSK1-H060A04B30E36
2181000001_綴裔_RSK1-H060A04B30S36
3231000003_勾板螺丝型6pin连接器插座_GAMC3063
小电机编码端子
60楊擘粣
3220000001_蚐猾_TC15x25x4(NBR)
3130000001_平键_B5x5x14(GBT1096-2003 带起键螺孔M3)
3111000001_内六角圆柱头螺钉_M2.5x10(GBT70.1-2000 锌镍合金 黑色 耐落 12.9级） x 4
3114000001_十字槽盘头自挤螺钉_M2x5(GBT6560-2014 锌镍合金 黑色) x 8
3111000002_内六角圆柱头螺钉_M2.5x40(GBT70.1-2000 锌镍合金 黑色 耐落 12.9级） x 4

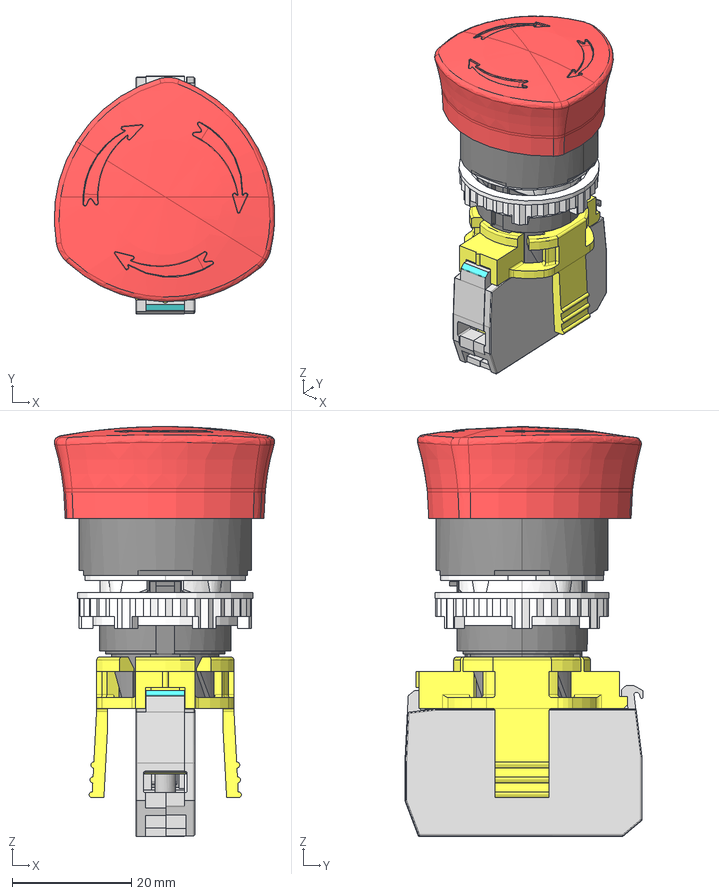
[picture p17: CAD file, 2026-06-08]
02_CAD/01_Standard_Parts/ImportTemp/L22ED01D/L22ED01D.stp
37.0 x 39.9 x 68.7 mm

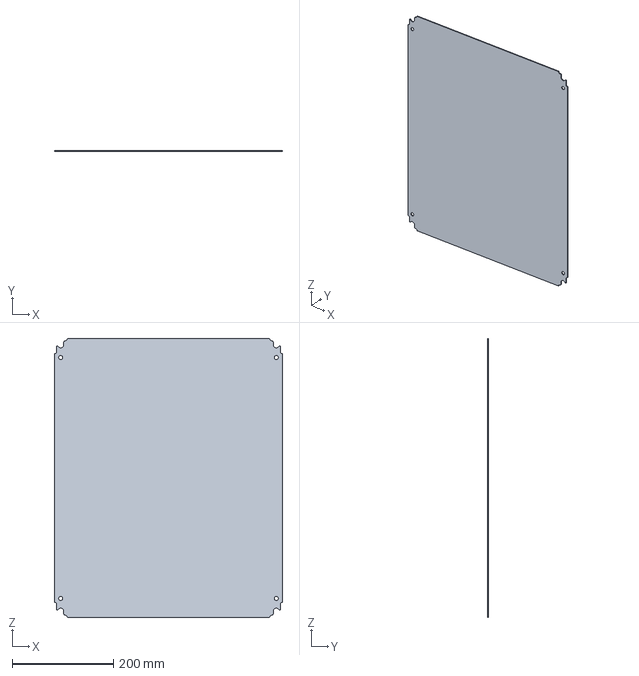
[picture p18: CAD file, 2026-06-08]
02_CAD/01_Standard_Parts/ImportTemp/MCADUE0002949_3D-simplified.stp
450.0 x 1.80 x 550.0 mm

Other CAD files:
02_CAD/01_Standard_Parts/ImportTemp/NF-R8_redux_Public-CAD/NF-R8_Public-CAD.stp
02_CAD/01_Standard_Parts/ImportTemp/PARTserver0202606071732142041179010e898ce/RTrident.stp
02_CAD/01_Standard_Parts/RAKO_600x400x220_40L.stp
02_CAD/00_Skeleton/OldVersions/RT_FRM_SK_001_RoughDim.0004.ipt
02_CAD/00_Skeleton/OldVersions/RT_FRM_SK_002_TopPlate.0001.ipt
02_CAD/00_Skeleton/RT_FRM_SK_001_RoughDim.ipt
02_CAD/01_Standard_Parts/02_FRM_Extrusions_Frame_V3/4080x600.ipt
02_CAD/01_Standard_Parts/02_FRM_Extrusions_Frame_V3/OldVersions/4040x700.0005.ipt
02_CAD/01_Standard_Parts/02_FRM_Extrusions_Frame_V3/OldVersions/4080x600.0005.ipt
02_CAD/01_Standard_Parts/02_FRM_Extrusions_Frame_V4/160160L.ipt
02_CAD/01_Standard_Parts/02_FRM_Extrusions_Frame_V4/40120x520.ipt
02_CAD/01_Standard_Parts/02_FRM_Extrusions_Frame_V4/40120x620.ipt
02_CAD/01_Standard_Parts/02_FRM_Extrusions_Frame_V4/40160x400.ipt
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

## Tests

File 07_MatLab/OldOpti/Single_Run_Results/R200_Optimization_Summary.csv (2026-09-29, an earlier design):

Bicep_Length_mm | Forearm_Length_mm | Reduction_Ratio | Configuration | Fastest_Cycle_Time_s | Max_Tracking_Error_mm
200 | 420 | 1 | L1-200 L2-420 R:1.0 (EC 90 flat Open Rotor 48V) | NaN | NaN
180 | 420 | 1 | L1-180 L2-420 R:1.0 (EC 90 flat Open Rotor 48V) | NaN | NaN
160 | 420 | 1 | L1-160 L2-420 R:1.0 (EC 90 flat Open Rotor 48V) | NaN | NaN
200 | 400 | 1 | L1-200 L2-400 R:1.0 (EC 90 flat Open Rotor 48V) | NaN | NaN
180 | 400 | 1 | L1-180 L2-400 R:1.0 (EC 90 flat Open Rotor 48V) | NaN | NaN
160 | 400 | 1 | L1-160 L2-400 R:1.0 (EC 90 flat Open Rotor 48V) | 0.7 | 9.87088281830036
200 | 380 | 1 | L1-200 L2-380 R:1.0 (EC 90 flat Open Rotor 48V) | NaN | NaN
180 | 380 | 1 | L1-180 L2-380 R:1.0 (EC 90 flat Open Rotor 48V) | NaN | NaN
160 | 380 | 1 | L1-160 L2-380 R:1.0 (EC 90 flat Open Rotor 48V) | NaN | NaN
200 | 360 | 1 | L1-200 L2-360 R:1.0 (EC 90 flat Open Rotor 48V) | NaN | NaN
180 | 360 | 1 | L1-180 L2-360 R:1.0 (EC 90 flat Open Rotor 48V) | NaN | NaN
160 | 360 | 1 | L1-160 L2-360 R:1.0 (EC 90 flat Open Rotor 48V) | NaN | NaN
200 | 340 | 1 | L1-200 L2-340 R:1.0 (EC 90 flat Open Rotor 48V) | NaN | NaN
180 | 340 | 1 | L1-180 L2-340 R:1.0 (EC 90 flat Open Rotor 48V) | NaN | NaN
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

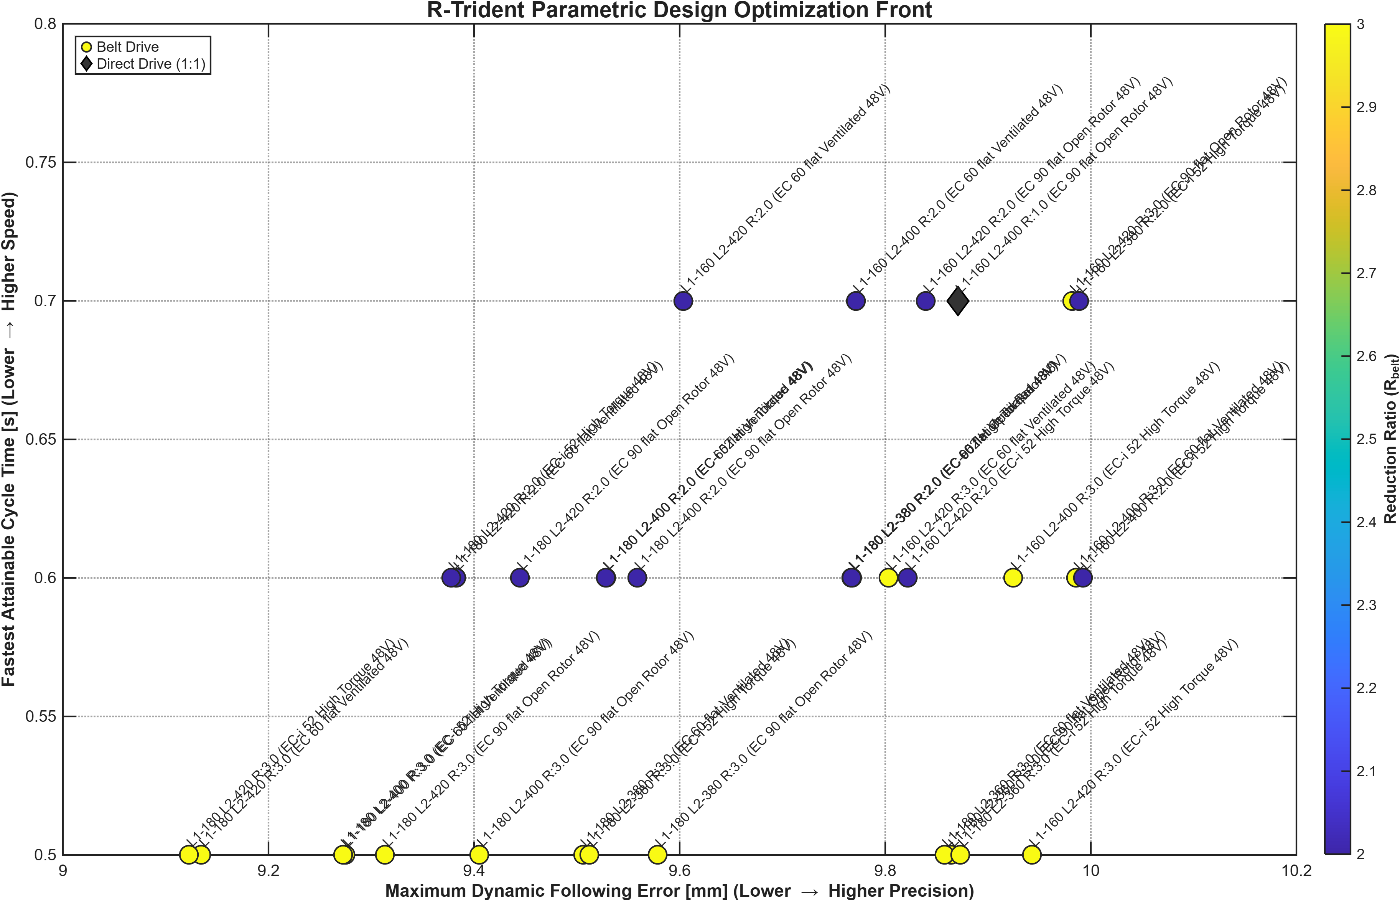
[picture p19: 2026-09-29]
07_MatLab/docs/img/Performance_Capabilities_05.png

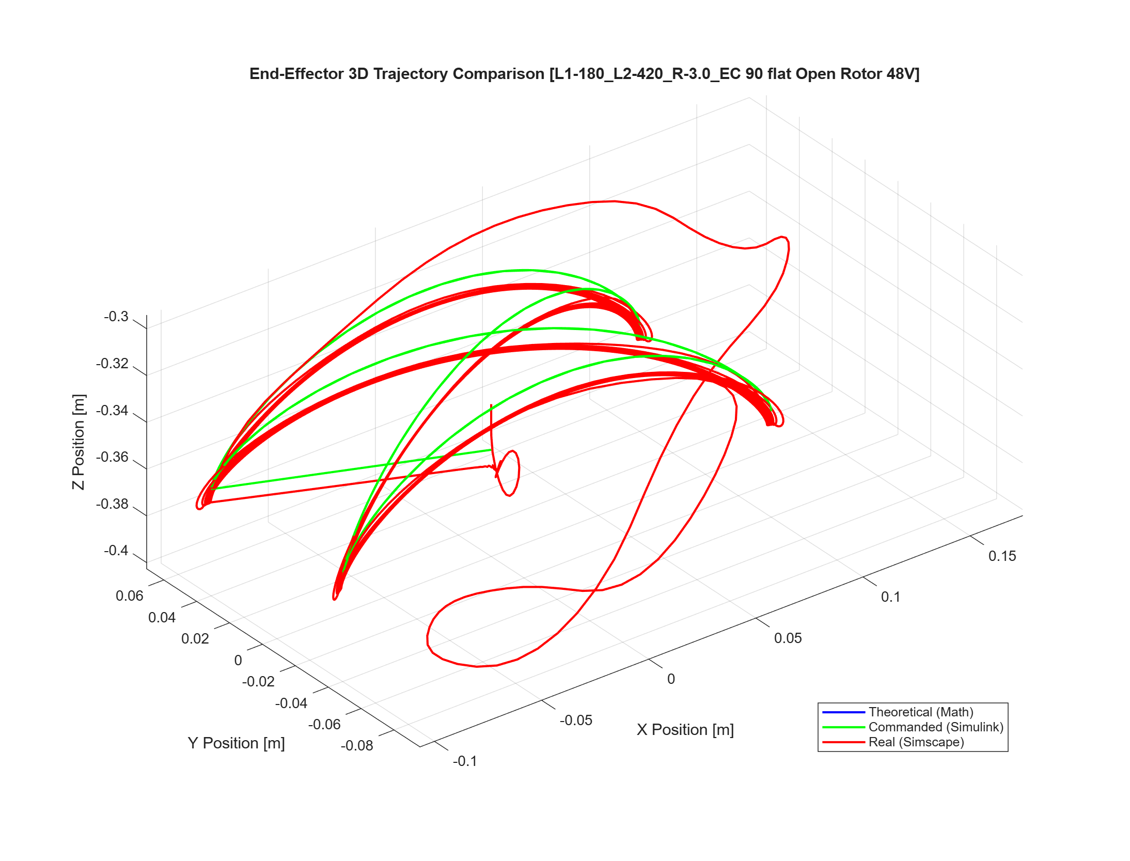
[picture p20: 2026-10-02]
07_MatLab/MotorValidation/Single_Run_Results/R200_L1-180_L2-420_R-3.0_EC 90 flat Open Rotor 48V/R200_L1-180_L2-420_R-3.0_EC 90 flat Open Rotor 48V_Trajectory3D.png

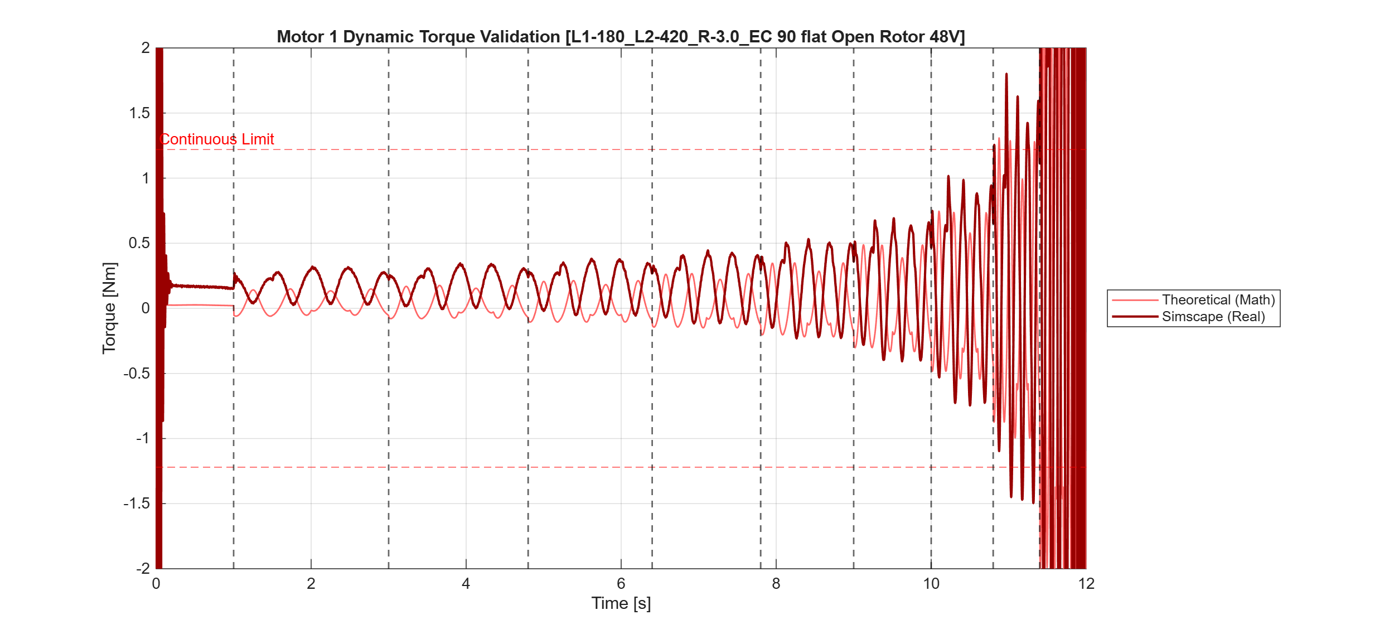
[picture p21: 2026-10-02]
07_MatLab/MotorValidation/Single_Run_Results/R200_L1-180_L2-420_R-3.0_EC 90 flat Open Rotor 48V/R200_L1-180_L2-420_R-3.0_EC 90 flat Open Rotor 48V_Dynamics_Motor1.png

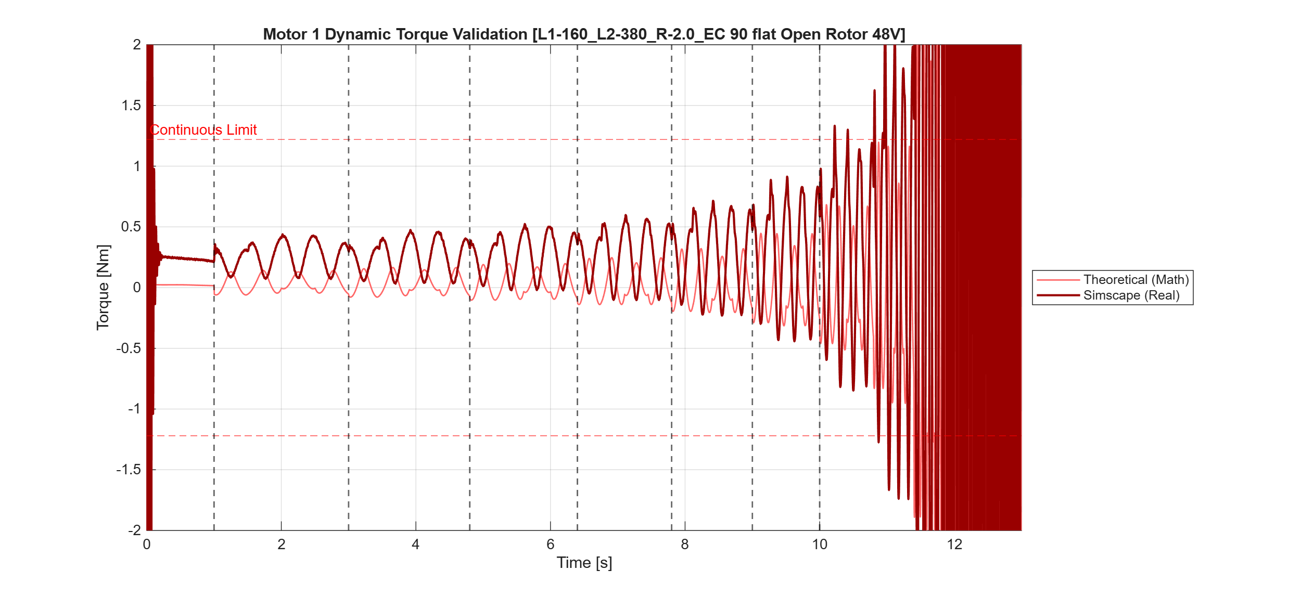
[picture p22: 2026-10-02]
07_MatLab/MotorValidation/Single_Run_Results/R200_L1-160_L2-380_R-2.0_EC 90 flat Open Rotor 48V/R200_L1-160_L2-380_R-2.0_EC 90 flat Open Rotor 48V_Dynamics_Motor1.png

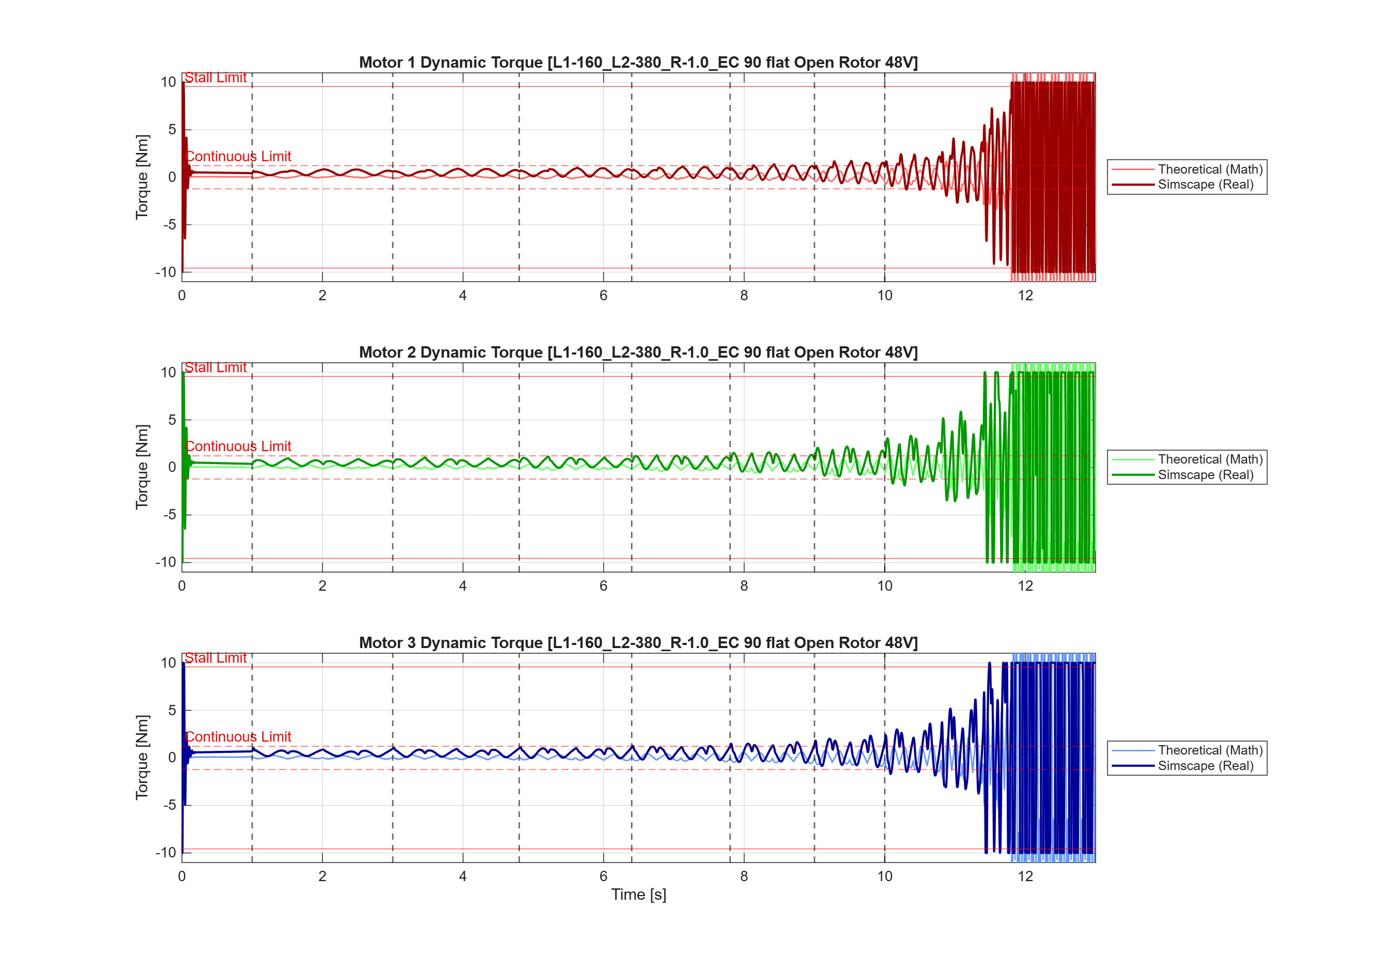
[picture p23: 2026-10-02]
07_MatLab/MotorValidation/Single_Run_Results/R200_L1-160_L2-380_R-1.0_EC 90 flat Open Rotor 48V/R200_L1-160_L2-380_R-1.0_EC 90 flat Open Rotor 48V_Dynamics.png

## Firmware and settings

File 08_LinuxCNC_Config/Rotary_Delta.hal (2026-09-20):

loadrt [KINS]KINEMATICS
loadrt motmod servo_period_nsec=1000000 num_joints=3

# 1. Parse XML and load EtherCAT driver
loadusr -W lcec_conf /home/r-trident/linuxcnc/configs/Rotary_Delta/ethercat-conf.xml
loadrt lcec

# 2. Load CiA402 driver for 3 servos
loadrt cia402 count=3

# 3. Thread Function Assignments (STRICT ORDER)
addf lcec.read-all servo-thread
addf cia402.0.read-all servo-thread
addf cia402.1.read-all servo-thread
addf cia402.2.read-all servo-thread
addf motion-command-handler servo-thread
addf motion-controller servo-thread
addf cia402.0.write-all servo-thread
addf cia402.1.write-all servo-thread
addf cia402.2.write-all servo-thread
addf lcec.write-all servo-thread

# ==========================================
# JOINT 0 (Axis 1)
# ==========================================
net j0-enable      joint.0.amp-enable-out => cia402.0.enable
setp cia402.0.pos-scale 364.088889

net j0-pos-cmd     joint.0.motor-pos-cmd  => cia402.0.pos-cmd
net j0-pos-fb      cia402.0.pos-fb        => joint.0.motor-pos-fb

net e0-statusword  lcec.0.servo_j0.statusword        => cia402.0.statusword
net e0-controlword cia402.0.controlword              => lcec.0.servo_j0.controlword
net e0-act-pos     lcec.0.servo_j0.position-actual  => cia402.0.drv-actual-position
net e0-tar-pos     cia402.0.drv-target-position     => lcec.0.servo_j0.target-position

# ==========================================
# JOINT 1 (Axis 2)
# ==========================================
net j1-enable      joint.1.amp-enable-out => cia402.1.enable
setp cia402.1.pos-scale 364.088889

net j1-pos-cmd     joint.1.motor-pos-cmd  => cia402.1.pos-cmd
net j1-pos-fb      cia402.1.pos-fb        => joint.1.motor-pos-fb

net e1-statusword  lcec.0.servo_j1.statusword        => cia402.1.statusword
net e1-controlword cia402.1.controlword              => lcec.0.servo_j1.controlword
net e1-act-pos     lcec.0.servo_j1.position-actual  => cia402.1.drv-actual-position
net e1-tar-pos     cia402.1.drv-target-position     => lcec.0.servo_j1.target-position

# ==========================================
# JOINT 2 (Axis 3)
# ==========================================
net j2-enable      joint.2.amp-enable-out => cia402.2.enable
setp cia402.2.pos-scale 364.088889

net j2-pos-cmd     joint.2.motor-pos-cmd  => cia402.2.pos-cmd
net j2-pos-fb      cia402.2.pos-fb        => joint.2.motor-pos-fb

net e2-statusword  lcec.0.servo_j2.statusword        => cia402.2.statusword
net e2-controlword cia402.2.controlword              => lcec.0.servo_j2.controlword
net e2-act-pos     lcec.0.servo_j2.position-actual  => cia402.2.drv-actual-position
net e2-tar-pos     cia402.2.drv-target-position     => lcec.0.servo_j2.target-position

# ==========================================
# WAGO BUTTON TO RELAY MAPPING
# ==========================================
net button-relay-link lcec.0.wago.t5-in-1 => lcec.0.wago.t1-out-1

# ==========================================
# AUTOMATIC MOTOR BRAKE RELEASE
# ==========================================
# Load an AND block to ensure ALL 3 drives are in "Operation Enabled" (active holding torque)
# before the 24V brake relay is allowed to release
loadrt and2 names=brakes_and1,brakes_and2
addf brakes_and1 servo-thread
addf brakes_and2 servo-thread

net j0-active cia402.0.stat-op-enabled => brakes_and1.in0
net j1-active cia402.1.stat-op-enabled => brakes_and1.in1
net j01-active brakes_and1.out         => brakes_and2.in0
net j2-active cia402.2.stat-op-enabled => brakes_and2.in1

# Only energize the WAGO relay (releasing the brake) when all 3 servos are stiff
net release-brakes brakes_and2.out => lcec.0.wago.t1-out-2

# ==========================================
# SAFETY LOOP
# ==========================================
net estop-loop iocontrol.0.user-enable-out => iocontrol.0.emc-enable-in

# ==========================================
# ROTARY DELTA GEOMETRY (mm)
# ==========================================
setp rotarydeltakins.footradius       90.0
setp rotarydeltakins.platformradius   22.5
setp rotarydeltakins.thighlength     150.0
setp rotarydeltakins.shinlength      335.0

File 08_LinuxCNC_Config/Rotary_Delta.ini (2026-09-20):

[EMC]
VERSION = 1.1
MACHINE = Delta-robot-with-rotary-joints
DEBUG = 0

[DISPLAY]
DISPLAY = axis
MAX_LINEAR_VELOCITY = 200.0
DEFAULT_LINEAR_VELOCITY = 50.0
MAX_FEED_OVERRIDE = 1.5
PROGRAM_PREFIX = ../../../nc_files/
INTRO_GRAPHIC = linuxcnc.gif
INTRO_TIME = 5
TOOL_EDITOR = tooledit
INCREMENTS = 1 in, 0.1 in, 10 mil, 1 mil
POSITION_OFFSET = RELATIVE
POSITION_FEEDBACK = COMMANDED

[FILTER]
PROGRAM_EXTENSION = .png,.gif,.jpg Grayscale Depth Image
PROGRAM_EXTENSION = .py Python Script
png = image-to-gcode
gif = image-to-gcode
jpg = image-to-gcode
py = python3

[TASK]
TASK = milltask
CYCLE_TIME = 0.001

[RS274NGC]
PARAMETER_FILE = sim.var

[EMCMOT]
EMCMOT = motmod
BASE_PERIOD  = 0
SERVO_PERIOD = 1000000

[HAL]
HALFILE = ./Rotary_Delta.hal
HALUI = halui

[TRAJ]
COORDINATES = X Y Z
AXES = 3
LINEAR_UNITS = mm
ANGULAR_UNITS = degree
CYCLE_TIME = 0.010
# Raise trajectory planner global caps
DEFAULT_LINEAR_VELOCITY = 50.0
MAX_LINEAR_VELOCITY = 200.0
MAX_ANGULAR_VELOCITY = 360.0
SERVO_PERIOD = 1000000
# Allow the trajectory planner to ramp up faster
MAX_ACCELERATION = 2000.0

[KINS]
KINEMATICS = rotarydeltakins
JOINTS = 3

#[KINS]
#KINEMATICS = trivkins coordinates=XYZ
#JOINTS = 3

[JOINT_0]
TYPE = ANGULAR

HOME = 0
HOME_OFFSET = 0.0
HOME_SEARCH_VEL = 0.0
HOME_LATCH_VEL = 0.0
HOME_FINAL_VEL = 00.0
HOME_SEQUENCE = 0
HOME_USE_INDEX = NO	
HOME_ABSOLUTE_ENCODER = 0

MAX_VELOCITY = 360
MAX_ACCELERATION = 10000.0
MIN_LIMIT = -99999.0
MAX_LIMIT = 99999.0

FERROR = 50.0
MIN_FERROR = 4.0

[JOINT_1]
TYPE = ANGULAR

HOME = 0
HOME_OFFSET = 0.0
HOME_SEARCH_VEL = 0.0
HOME_LATCH_VEL = 0.0
HOME_FINAL_VEL = 00.0
HOME_SEQUENCE = 0
HOME_USE_INDEX = NO
HOME_ABSOLUTE_ENCODER = 0

MAX_VELOCITY = 360
MAX_ACCELERATION = 10000.0
MIN_LIMIT = -99999.0
MAX_LIMIT = 99999.0

FERROR = 50.0
MIN_FERROR = 4.0

[JOINT_2]
TYPE = ANGULAR

HOME = 0
HOME_OFFSET = 0.0
HOME_SEARCH_VEL = 0.0
HOME_LATCH_VEL = 0.0
HOME_FINAL_VEL = 00.0
HOME_SEQUENCE = 0
HOME_USE_INDEX = NO
HOME_ABSOLUTE_ENCODER = 

MAX_VELOCITY = 360
MAX_ACCELERATION = 10000.0
MIN_LIMIT = -99999.0
MAX_LIMIT = 99999.0

FERROR = 50.0
MIN_FERROR = 4.0

[AXIS_X]
MAX_VELOCITY = 200
MAX_ACCELERATION = 2000
MIN_LIMIT = -99999.0
MAX_LIMIT = 99999.0

[AXIS_Y]
MAX_VELOCITY = 200
MAX_ACCELERATION = 2000
MIN_LIMIT = -99999.0
MAX_LIMIT = 99999.0

[AXIS_Z]
MAX_VELOCITY = 200
MAX_ACCELERATION = 2000
MIN_LIMIT = -99999.0
MAX_LIMIT = 99999.0

[EMCIO]
EMCIO = io
CYCLE_TIME = 0.1
TOOL_TABLE = sim.tbl

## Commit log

2026-04-19 Update enclosure description in README
2026-04-19 SK of general dim
    [RT_FRM_SK_001_ReferanceSpreadsheet.xlsx, RT_FRM_SK_001_RoughDim.ipt]
2026-04-28 Work on Bicep
    [00-ASM-SIFU-QUDONG_ASM.iam, 2142000001_»ú¿ÇÃ«Å÷_RSK1-H060A04B30S36.ipt, 2174000002_ºó¶Ë¸ÇÃ«Å÷_RSK1-H060A04B30E36.ipt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]
2026-05-10 Simulink Model ADDED
    [2142000001_»ú¿ÇÃ«Å÷_RSK1-H060A04B30S36.0001.ipt, 2142000001_»ú¿ÇÃ«Å÷_RSK1-H060A04B30S36.ipt, 2174000002_ºó¶Ë¸ÇÃ«Å÷_RSK1-H060A04B30E36.0001.ipt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]
2026-05-12 Update to Simulink and Inventor
    [2142000001_»ú¿ÇÃ«Å÷_RSK1-H060A04B30S36.0001.ipt, 2142000001_»ú¿ÇÃ«Å÷_RSK1-H060A04B30S36.0002.ipt, 2142000001_»ú¿ÇÃ«Å÷_RSK1-H060A04B30S36.ipt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]
2026-05-25 Big cahnages and additions to the CAD and MatLab
    [2026_05_12_10_23_57_0836.ipt, 2026_05_12_10_23_57_0851.ipt, 2026_05_12_10_23_57_0867.ipt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]
2026-06-05 Updated frame
    [3532_20210408113519_4080L + cover.0002.iam, 3532_20210408113519_4080L + cover.STEP, 3532_20210408113519_4080L + cover.iam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]
2026-06-06 large changes to the inverse kinematics block
    [3532_20210408113519_4080L + cover.0002.iam, 3532_20210408113519_4080L + cover.0003.iam, 3532_20210408113519_4080L + cover.iam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]
2026-06-08 Major cad over haul
    [00-ASM-SIFU-QUDONG_ASM.iam, 0172001.iam, 0172001.stp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]
2026-06-25 Cad and Matlab
    [40120x620.0002.ipt, 40120x620.0003.ipt, 40120x620.ipt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]
2026-07-01 Introduction of a test bench
    [MW_WDR_240_24.0001.ipt, MW_WDR_240_24.ipt, RAKO_600x400x220_40L.ipt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]
2026-07-10 Updating the control cabinet and introducing topology-optimized biceps
    [4040Square.dxf, 4040Square.ipt, 4060Rect.dxf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]
2026-07-29 Major frame changes
    [160160L.ipt, 3714_20210320155134_8-13.40.STEP, 3714_20210320155138_8-13.40 Cover.STEP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]
2026-07-31 New addition of cables and some other tweaks
    [280-519_LO.0002.ipt, 280-519_LO.ipt, 3760_20240902141114_4040L-ALU.STEP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]
2026-08-06 new pi5 to the automation
    [8617_540.0001.iam, 8617_540.iam, 8617_540_P1.ipt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]
2026-08-15 fram and power changes
    [4040x620.0007.ipt, 4040x620.ipt, 8617_540.0001.iam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]
2026-09-17 Add Rotary Delta LinuxCNC configuration to 08_LinuxCNC_Config
    [Rotary_Delta-motor.hal, Rotary_Delta.hal, Rotary_Delta.ini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]
2026-09-17 Auto-backup Rotary Delta config: 2026-09-17 18:28:29
    [Rotary_Delta.hal]
2026-09-17 Sync Rotary Delta configs from LinuxCNC
    [Rotary_Delta.hal, Rotary_Delta.ini]
2026-09-20 Auto-backup Rotary Delta config: 2026-09-20 17:22:06
    [Rotary_Delta.hal, Rotary_Delta.ini]
2026-09-20 Auto-backup Rotary Delta config: 2026-09-20 19:08:51
    [Rotary_Delta.hal, Rotary_Delta.ini]
2026-09-23 Continuation o Testbench
    [RT_FRM_MC_V3_MotorBase.ipt, RT_FRM_MC_V3_MotorBase.stp, RT_FRM_V2_MC_004_TopDynamicsPlate.0009.ipt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]
2026-09-24 New Frame
    [1200_Profile_40L.ipt, 270_Profile_40L.ipt, 540_Profile_40L.ipt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]
2026-09-27 Full opti runs
    [R_Trident_Optimization_Summary.csv]
2026-09-28 Fixed Angle Limitation
    [R_Trident_Optimization_Summary.csv]
2026-09-29 End of R200 opti
    [R_Trident_Optimization_Summary.csv]
2026-09-29 Final Opti
    [R_Trident_Optimization_Summary.csv, Tep.ipt]
2026-10-02 New path generator
    [R200_Optimization_Summary.csv]
